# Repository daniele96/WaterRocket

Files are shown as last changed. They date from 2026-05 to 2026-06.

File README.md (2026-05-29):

# Water Rocket 🚀💧

Progetto di un razzo ad acqua (water rocket): documentazione completa di fisica,
componenti, materiali, calcoli, costruzione, lancio, sicurezza, risorse e stampa 3D.

## 📄 Documentazione

La guida completa è in **[WaterRocket.md](WaterRocket.md)** e include:

- **Come funziona** — principio di azione-reazione e formule della spinta
- **Componenti** — corpo, ugello, ogiva, alette, zavorra, sistema di lancio
- **Materiali** — lista della spesa
- **Parametri di progetto** — riempimento, pressione, stabilità (CG vs CP)
- **Calcoli rapidi** — velocità di espulsione, frazione d'acqua ottimale
- **Costruzione** — passo-passo
- **Lancio e test** — procedura e tabella raccolta dati
- **Sicurezza** ⚠️
- **Link di documentazione** — risorse verificate (NASA, Air Command, WRA2, ...)
- **Stampa 3D** 🖨️ — cosa stampare, materiali e dove trovare i modelli STL

## ⚠️ Sicurezza

L'aria compressa è pericolosa. Usa solo bottiglie PET per bibite gassate, non superare
le pressioni consigliate, indossa occhiali protettivi e lancia all'aperto lontano da
persone. Attività per ragazzi solo sotto supervisione adulta.

## 🚦 Stato

Progetto in fase di documentazione/progettazione.

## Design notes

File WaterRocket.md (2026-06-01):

# Progetto Water Rocket 🚀💧

Documento di progettazione per un razzo ad acqua (water rocket): principi fisici,
componenti, materiali, calcoli, costruzione, lancio e sicurezza.

---

## 1. Come funziona

Un water rocket sfrutta il **principio di azione-reazione** (3ª legge di Newton).
La bottiglia viene riempita parzialmente d'acqua e pressurizzata con aria.
All'apertura del tappo, l'aria compressa spinge fuori l'acqua ad alta velocità:
l'espulsione della massa d'acqua genera una spinta che accelera il razzo verso l'alto.

Equazione della spinta (semplificata):

```
F = ṁ · v_e        (massa espulsa al secondo × velocità di espulsione)
v_e = sqrt(2 · ΔP / ρ_acqua)
```

dove:
- `ΔP` = differenza di pressione tra interno bottiglia e atmosfera [Pa]
- `ρ_acqua` ≈ 1000 kg/m³

---

## 2. Componenti principali

| Componente | Funzione |
|---|---|
| **Corpo (bottiglia)** | Serbatoio pressione + acqua. PET da bibita gassata |
| **Ugello (nozzle)** | Apertura del tappo da cui esce l'acqua |
| **Ogiva (nose cone)** | Punta aerodinamica, riduce la resistenza |
| **Alette (fins)** | Stabilità aerodinamica in volo |
| **Zavorra** | Massa in punta per spostare il baricentro avanti  |
| **Sistema di lancio** | Tappo di tenuta + meccanismo di rilascio |
| **Recupero (opzionale)** | Paracadute per atterraggio dolce |

---

## 3. Materiali (lista della spesa)

- 1–2 **bottiglie PET** da 1,5 L o 2 L (per bibite gassate — resistono alla pressione)
- **Cartoncino / polipropilene / Depron** per le alette
- **Pallina da tennis** o cono in cartoncino per l'ogiva
- **Nastro adesivo resistente** (telato/Tesa) e **colla a caldo**
- **Plastilina o sabbia** per la zavorra
- **Tappo forato + valvola** (es. tappo gonfiabile / adattatore per pompa)
- **Pompa da bicicletta** con manometro
- **O-ring / guarnizione** per la tenuta
- Fascette, tubo in PVC per la rampa di lancio

---

## 4. Parametri di progetto consigliati

| Parametro | Valore tipico / di partenza |
|---|---|
| Volume bottiglia | 1,5 – 2 L |
| Riempimento d'acqua | **~1/3 del volume (25–40%)** |
| Pressione di lancio | 4 – 6 bar (max ~8 bar con PET) |
| N° alette | 3 o 4, distribuite simmetricamente |
| Posizione baricentro (CG)  | **davanti** al centro di pressione (CP) |
| Margine di stabilità | CG-CP ≈ 1–2 calibri (diametri) |

> ⚠️ **Regola d'oro stabilità:** il baricentro (CG) deve stare *davanti* (verso
> l'ogiva) rispetto al centro di pressione aerodinamica (CP). Per questo si aggiunge
> zavorra in punta. Verifica con la "prova della cordicella": appendi il razzo
> orizzontalmente al CG e fallo ruotare — deve volare con la punta in avanti.

---

## 5. Calcoli rapidi

**Velocità di espulsione acqua** (a 6 bar = 600 000 Pa):
```
v_e = sqrt(2 · 600000 / 1000) ≈ 34,6 m/s
```

**Stima frazione d'acqua ottimale:** il massimo della quota si ottiene quando c'è
abbastanza acqua da spingere a lungo, ma non così tanta da appesantire il razzo.
In pratica **~30% del volume** è un ottimo punto di partenza; ottimizza con i test.

**Quota:** dipende da pressione, massa a vuoto, aerodinamica e attrito.
Per simulazioni più precise puoi usare un foglio di calcolo o software dedicati
(vedi sezione 8).

---

## 6. Costruzione (passo-passo)

1. **Corpo:** scegli una bottiglia integra, senza ammaccature o graffi profondi.
2. **Alette:** ritaglia 3–4 alette identiche; incollale a 120° (o 90°) vicino
   all'ugello, ben allineate all'asse. Allineamento preciso = volo dritto.
3. **Ogiva:** fissa il cono/pallina in punta; inserisci la zavorra all'interno.
4. **Tenuta:** monta il tappo con valvola e o-ring; verifica che tenga la pressione.
5. **Bilanciamento:** trova il CG e controlla il margine di stabilità (sez. 4).
6. **Recupero (opz.):** aggiungi un paracadute con meccanismo a tempo o aerodinamico.

---

## 7. Lancio e procedura di test

1. Posiziona la rampa su terreno aperto, lontano da persone, edifici, linee elettriche.
2. Riempi d'acqua (~1/3) e fissa il razzo al sistema di lancio.
3. Pressurizza **gradualmente** controllando il manometro.
4. **Allontana tutti** ad almeno 5–10 m. Conto alla rovescia.
5. Rilascia da distanza di sicurezza (cordino/leva).
6. **Registra i dati** ad ogni lancio per ottimizzare:

| Lancio | Acqua (%) | Pressione (bar) | Massa (g) | Quota stimata (m) | Note |
|---|---|---|---|---|---|
| 1 | | | | | |
| 2 | | | | | |
| 3 | | | | | |

---

## 8. Strumenti utili

- **Simulatori:** *Water Rocket Fun*, *Clive's Water Rocket Simulator*, fogli Excel dedicati.
- **Misura quota:** app inclinometro + triangolazione, o altimetro a bordo (es. modulo BMP280).
- **Slow motion** dello smartphone per analizzare il distacco e la traiettoria.

---

## 9. ⚠️ Sicurezza (leggere SEMPRE)

- L'aria compressa è **pericolosa**: una bottiglia che cede a 6 bar può ferire.
- Usa **solo** bottiglie PET per bibite gassate, mai bottiglie danneggiate o riutilizzate troppe volte.
- **Non superare** le pressioni consigliate; non sostare mai sopra/davanti al razzo carico.
- Indossa **occhiali protettivi** durante la pressurizzazione.
- Lancia all'aperto, lontano da persone, animali e ostacoli. Mai al chiuso.
- Attività adatta a ragazzi **solo sotto supervisione adulta**.

---

## 10. Idee di miglioramento

- Razzo **bi-stadio** (due bottiglie in sequenza).
- **Tromboncino/booster** con bottiglie unite per più volume.
- Sistema di **recupero a paracadute** automatico.
- **Telemetria** a bordo (altimetro, accelerometro, GPS).
- Ottimizzazione aerodinamica dell'ogiva e delle alette.

---

## 11. Link di documentazione e risorse

> ⚠️ Gli URL possono cambiare nel tempo: se un link è morto, cerca il nome del sito/progetto.

### Guide, teoria e community
- **NASA – Water Rocket / Bottle Rocket** (principi fisici e attività didattiche):
  <https://www.grc.nasa.gov/www/k-12/rocket/BottleRocket/about.htm>
- **Air Command Water Rockets** (uno dei riferimenti storici più completi,
  con build avanzate, multistadio, recupero): <https://www.aircommandrockets.com/>
  - Quanta acqua mettere: <http://www.aircommandrockets.com/water.htm>
  - Costruire un lanciatore: <http://www.aircommandrockets.com/rocket_launcher.htm>
  - Costruzione del razzo: <http://www.aircommandrockets.com/construction.htm>
  - Meccanismo di recupero paracadute (DetMech): <http://www.aircommandrockets.com/howitworks_3.htm>
  - Galleria progetti: <http://www.aircommandrockets.com/rocket_gallery.htm>
  > Nota: il sito funziona anche su `http://` se l'`https://` dà problemi.
- **NPL / The Water Rocket Achievement World Record Association (WRA2)**
  (record, regole, tecnica): <https://www.wra2.org/>
- **r/WaterRockets** (community Reddit con build e consigli):
  <https://www.reddit.com/r/WaterRockets/>
- **Wikipedia – Water rocket** (panoramica generale e riferimenti):
  <https://en.wikipedia.org/wiki/Water_rocket>

### Simulatori e calcolo
- **Clive's Water Rocket Simulator (Excel)** — molto usato per stimare quota e profilo di volo.
- **OpenRocket** (più orientato ai razzi a propellente solido, ma utile per concetti di
  stabilità/CG-CP): <https://openrocket.info/>
- **Water Rocket Fun** — app/simulatore per il calcolo del riempimento ottimale.

### Video tutorial (cerca su YouTube)
- "Water rocket build" / "water rocket launcher Gardena" (lanciatore con attacco rapido da giardino)
- "Water rocket parachute deployment" per i sistemi di recupero
- Canale **Air Command Rockets** su YouTube

---

## 12. Stampa 3D 🖨️

La stampa 3D è perfetta per le parti **non in pressione**: ogiva, alette, anelli
fermaaletta, adattatori per la rampa e meccanismi di recupero. **La camera in pressione
deve restare la bottiglia PET** (il PLA/PETG stampato non è affidabile per contenere
4–8 bar).

### Cosa conviene stampare
| Parte | Materiale consigliato | Note |
|---|---|---|
| Ogiva / nose cone | PLA o PETG | Leggera; eventualmente cava per zavorra |
| Anello porta-alette (fin can)| PETG / ABS / ASA | Si infila sul collo o sul corpo |
| Alette | PETG / PLA | Anche stampabili a parte e incastrate |
| Adattatore ugello / launcher | PETG / ABS | Per accoppiare la rampa al collo bottiglia |
| Vano paracadute / nose lock  | PLA / PETG | Per il sistema di recupero |

> Per parti soggette a sole e calore preferisci **PETG/ASA** (il PLA si deforma al caldo
> e diventa fragile dopo gli urti).

### Dove trovare i modelli (STL già pronti)
- **Printables** (Prusa): <https://www.printables.com/> → cerca *"water rocket"*, *"water rocket fins"*, *"nose cone"*
- **Thingiverse**: <https://www.thingiverse.com/search?q=water+rocket> → moltissimi fin can e ogive
- **Thangs**: <https://thangs.com/> → motore di ricerca multi-piattaforma di modelli 3D
- **MakerWorld** (Bambu Lab): <https://makerworld.com/> → cerca *"water rocket"*
- **Cults3D**: <https://cults3d.com/> → modelli gratuiti e a pagamento
- **GrabCAD** (modelli CAD parametrici, utili da modificare):
  <https://grabcad.com/library> → cerca *"water rocket"*

### Termini di ricerca utili
`water rocket fins`, `water rocket nose cone`, `bottle rocket fin can`,
`water rocket launcher adapter`, `Gardena water rocket launcher`,
`PET bottle rocket parachute`, `water rocket coupling 2 liter`.

### Suggerimenti di stampa
- Stampa le alette **piatte sul piatto** per la massima resistenza lungo la corda.
- Per il fin can usa **alta densità di riempimento** vicino agli attacchi (o pareti spesse).
- Modella l'**interno dell'ogiva cavo** per inserire la zavorra (plastilina/sabbia) e
  regolare il baricentro.
- Verifica il **diametro del collo bottiglia standard PCO-1810/PCO-1881** quando progetti
  adattatori parametrici.

---

## 13. Elettronica di bordo 🔌

Sistema di telemetria + log dati + video da montare nell'**ogiva** del razzo
(scende col paracadute passivo del kit — vedi §3 e nota sotto).

### Architettura

- **MCU di volo**: ESP32-S3 con camera, in ogiva
- **Sensori I2C** sullo stesso bus: BMP280 + MPU6050
- **Storage**: microSD per log ad alta frequenza + video
- **Recupero**: passivo (paracadute del kit) + buzzer ritrovamento
- **Telemetria**: WiFi/BLE live a terra (range utile ~50 m)

### Board scelta: Seeed XIAO ESP32-S3 Sense

| Caratteristica | Valore |
|---|---|
| Dimensioni / peso | 21×17,5 mm, ~3 g |
| Camera | OV2640 2 MP (staccabile, opz. OV5640) |
| Microfono | PDM digitale |
| microSD slot | Sì, sulla shield camera |
| PSRAM / Flash | 8 MB / 8 MB |
| Carica LiPo | Sì, pad **BAT+/BAT-** da saldare |
| Wireless | WiFi 2,4 GHz + BLE 5.0, antenna ceramica + IPEX |
| Riferimento firmware | usata dal progetto `tritonFC` |

### Sensori e funzionalità sbloccate

| Sensore | Bus | Cosa abilita | Priorità |
|---|---|---|---|
| **BMP280** | I2C | Quota live, apogeo, profilo di volo, T/P cabina | ⭐⭐⭐ |
| **MPU6050** | I2C | Accelerazione lancio, giroscopio (roll/yaw/pitch), rilevazione apogeo via segno accel | ⭐⭐⭐ |
| **microSD** (slot integrato) | SPI | Log ≥100 Hz + video AVI | ⭐⭐⭐ |
| **Camera OV2640** | DVP | Video 640×480 a 15–25 fps, foto, analisi traiettoria | ⭐⭐ |
| **Buzzer passivo** | GPIO PWM | Beep ritrovamento + codici di stato | ⭐⭐ |
| **LED ultra-bright** | GPIO | Visibilità slow-mo, stato armato/disarmato | ⭐ |
| **Microfono PDM** | I2S | Acustica del getto d'acqua, evento apertura paracadute | ⭐ |
| **RTC DS3231** (lab) | I2C | Timestamp assoluti, sincronizzazione multi-razzo | ⭐ |
| **BH1750 / TSL2591** (lab) | I2C | Profilo luminosità lungo la traiettoria (didattico) | ⭐ |
| **GPS NEO-M8N** | UART | Ritrovamento a distanza (≥70 m). Costa ~20 g | ⭐ opz |
| **ADXL375 ±200 g** | I2C | Vero picco accel lancio + impatto (MPU6050 satura a ±16 g) | ⭐ opz |

### Schema collegamenti minimo

```
XIAO ESP32-S3 Sense
├── I2C (SDA/SCL)
│   ├── BMP280   (addr 0x76 o 0x77)
│   └── MPU6050  (addr 0x68)
├── microSD       → slot integrato (shield camera)
├── Camera OV2640 → FPC dedicato
├── BAT+ / BAT-   → LiPo 1S 300–400 mAh (saldatura)
├── GPIO          → buzzer passivo + LED
└── USB-C         → programmazione + ricarica
```

### Sensori del lab da NON portare in volo

| Sensore | Perché no | Uso alternativo |
|---|---|---|
| DHT11 | Risposta 2 s, volo dura ~5 s | Stazione meteo a terra |
| MQ-135 | Preriscaldo 30 s, alto consumo | Stazione a terra |
| LiPo 2000 mAh | ~40 g, penalizza la quota | Ground station / banco |

### Posizionamento meccanico

Elettronica **nell'ogiva** (verde del kit AliExpress, o sostitutiva stampata 3D più
capiente — vedi §12). L'ogiva si stacca all'apogeo per inerzia, gli elastici cedono
e tira fuori il paracadute; scende legata al corpo via shock cord. **Annegare PCB e
LiPo in spugna densa** dentro un vano dedicato. LiPo **sempre fissata** con biadesivo
o fascette, mai libera.

### Architettura firmware suggerita

Sposa il modello didattico "un gruppo = un sensore" con task FreeRTOS separati:

```
[Task BMP280] ─┐
[Task MPU6050]─┼→ [Queue dati] → [Task Logger SD] + [Task Telemetria WiFi/BLE]
[Task Camera] ─┘
```

**Firmware di riferimento (open source):**
- **[zerneo85/ESP-Controlled-Rocket](https://github.com/zerneo85/ESP-Controlled-Rocket)** (GPL-3.0, attivo): BMP280 + MPU6050, Web UI, WebSocket live, 3D viewer, log SD. **Punto di partenza consigliato.**
- **[MaelStudio/tritonFC](https://github.com/MaelStudio/tritonFC)**: gira nativamente su XIAO ESP32-S3 Sense, gestisce video AVI, PCB di riferimento.
- **[nodebotsau/water-rocket](https://github.com/nodebotsau/water-rocket)** (MIT): ground station Node.js + MQTT, riusabile.

---

## 14. Acquisti e inventario 🛒

### Hardware fisico (razzo + lanciatore)

- [Kit lanciatore + paracadute AliExpress](https://it.aliexpress.com/item/1005008517820572.html)
  — paracadute passivo a *nose-cone pop-off*, fino a ~50–70 m reali

### Da acquistare (kit volante elettronica) — ~71 €

| # | Articolo | Q.tà | € | Link |
|---|---|---|---|---|
| 1 | **Seeed XIAO ESP32-S3 Sense** | 2 | 34 | [Amazon.it ✓](https://www.amazon.it/Seeed-Studio-XIAO-ESP32S3-Sense/dp/B0C69FFVHH) |
| 2 | **LiPo 1S 300–400 mAh JST 1.25** | 2 | 12 | [Amazon.it](https://www.amazon.it/s?k=LiPo+1S+400mAh+JST+1.25) · [AliExpress](https://it.aliexpress.com/w/wholesale-lipo-1s-400mah-jst-1.25.html) |
| 3 | **MPU6050 / GY-521** | 2 | 8 | [Amazon.it](https://www.amazon.it/s?k=GY-521+MPU6050) · [AliExpress](https://it.aliexpress.com/w/wholesale-gy-521-mpu6050.html) |
| 4 | **Buzzer passivo 5V** (multipack) | 1 kit | 6 | [Amazon.it](https://www.amazon.it/s?k=buzzer+passivo+5V+arduino) |
| 5 | **Antenna IPEX 2.4 GHz** (opzionale) | 2 | 6 | [Amazon.it](https://www.amazon.it/s?k=antenna+IPEX+UFL+2.4GHz) · [Seeed ufficiale](https://www.seeedstudio.com/2-4GHz-2-81dBi-Antenna-for-XIAO-ESP32C3-p-5475.html) |
| 6 | **LED + resistenze** (se mancanti) | 1 kit | 5 | [Amazon.it](https://www.amazon.it/s?k=led+kit+5mm+arduino) |
| | | **Totale** | **~71 €** | |

### Già in possesso (riusabile per il razzo)

| Pezzo | Q.tà | Uso nel razzo |
|---|---|---|
| ✅ BMP280 breakout | 5 | Altimetria di volo |
| ✅ microSD 32 GB | 5 | Log + video (slot della XIAO Sense) |
| ✅ ESP32-S3 DevKitC-1 (DUBEUYEW) | 2 | Ground station, test a banco, kit didattici |
| ✅ Freenove ESP32-WROVER + camera | 1 | Ground station / test pipeline camera |
| ✅ TTGO T-Display | 1 | Display a terra per telemetria live |
| ✅ BH1750, TSL2591 (luce) | 3 + 1 | Sensori opzionali (didattica) |
| ✅ RTC DS3231 | 5 | Timestamp log (opzionale) |
| ✅ LiPo 2000 mAh JST 1.25 | 4 | **Solo ground station** — troppo pesanti per volare |
| ✅ Breadboard + jumper + USB-C | — | Prototipazione |
| ✅ Stagno | — | Saldature (pad BAT della XIAO) |

### Sensori del lab esclusi dal volo

❌ DHT11, MQ-135, LiPo 2000 mAh, pannello solare — vedi §13 *"da NON portare in volo"*.

---

*Buoni lanci! 🚀*
```

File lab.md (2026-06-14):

# Laboratorio Water Rocket per Bambini e Ragazzi 🚀

Programma di laboratorio per evento didattico in cui i partecipanti
**assemblano, decorano e lanciano il proprio water rocket** a partire dal kit
acquistato ([AliExpress 1005008517820572](https://it.aliexpress.com/item/1005008517820572.html)).

Documento operativo per educatori/animatori. Per la teoria fisica e le specifiche
tecniche del razzo vedi [WaterRocket.md](WaterRocket.md).

---

## 0. Quadro generale

| Parametro | Valore di partenza |
|---|---|
| Età target | 8–14 anni |
| Dimensione gruppi | 3–4 bambini per razzo |
| **N° gruppi per sessione** | **4–6** (massimo gestibile da 1 educatore in 2h) |
| **Durata sessione** | **2 h** (incluso lancio e debrief) |
| **Bambini per sessione** | 12–24 |
| **Lanci per razzo** | **1–2** (un lancio principale, eventuale bis se c'è tempo) |
| **Scalabilità** | Sessioni **parallele** o **sfalsate** se più bambini — vedi §10 |
| Spazio richiesto | Aula/cortile per assemblaggio + campo aperto ≥30×30 m per lanci |
| Supervisione adulta | **Obbligatoria** durante pressurizzazione e lancio |

**Decisione aperta:** uso del **paracadute** (incluso nel kit) ancora da confermare.
Le fasi sotto sono pensate per funzionare **in entrambi gli scenari** — vedi
note specifiche in §5.

---

## 1. Materiali per il lab (per gruppo)

### Forniti dal kit AliExpress
- Bottiglia (da portare separatamente — PET 1,5 L o 2 L da bibita gassata)
- Ogiva verde + elastici di tenuta
- Paracadute (opzionale a discrezione organizzazione)
- Lanciatore manuale condiviso tra i gruppi

### Da preparare in stazione lab

| Materiale | Quantità per gruppo | Note |
|---|---|---|
| **Cartone ondulato da imballo** | 1 scatola A4 | Per pinne — riciclato, gratis (vedi §4) |
| **Nastro da pacchi trasparente** (larghezza 5 cm) | 1 rotolo condiviso | Laminatura pinne (impermeabilizzazione) |
| **Sagome pinne stampate** | 3 modelli (S/M/L) | Cartamodello pre-disegnato |
| **Striscia di carta** 3×35 cm + matita | 1 | Per metodo della striscia (vedi §4) — adattabile a qualsiasi bottiglia |
| **Washi tape colorato** | 2–3 rotoli | Decoro corpo |
| **Pennarelli Posca / Sharpie oil** | Set condiviso | Scrivere su PET |
| **Bi-adesivo schiumoso (foam tape)** | 1 striscia 30 cm | Incollaggio pinne, sicuro |
| **Plastilina pre-pesata** | Bustine da 10 / 20 / 30 g | Zavorra ogiva |
| **Spago + nastro** | 1 m | Per test della cordicella |
| **Forbici a punta tonda** | 2–3 | Sicurezza bambini, tagliano anche il cartone |

---

## 2. Struttura del laboratorio (sessione singola 2 h)

Sequenza compatta per 4–6 gruppi in 120 minuti netti.

```
[Briefing iniziale]                10'
   ↓
[Stazione 1: Pinne]                25'
   ↓
[Stazione 2: Decoro & identità]    20'
   ↓
[Stazione 3: Bilanciamento]        15'
   ↓
[Spostamento al campo lanci]        5'
   ↓
[Stazione 4: Lancio (4-6 razzi)]   35'
   ↓
[Debrief + dati]                   10'
─────────────────────────────────────
TOTALE                            120'
```

| Fase | Durata | Note per restare nei tempi |
|---|---|---|
| Briefing | 10' | Cartelloni pre-pronti, demo palloncino veloce |
| Pinne | 25' | Sagome pre-tagliate dall'organizzatore + bi-adesivo (no colla a caldo) |
| Decoro | 20' | Stop netto allo scadere — è la fase che dilata di più |
| Bilanciamento | 15' | Plastilina pre-pesata in bustine, test della cordicella rapido |
| Lancio | 35' | ~6 min per razzo (riempimento + pressurizzazione + lancio + reset) |
| Debrief | 10' | Tabella dati su lavagna, foto di gruppo |

> ⚠️ **Se hai 5–6 gruppi non puoi compressare il lancio sotto i 30–35 min** senza
> sacrificare sicurezza. Se vuoi più gruppi per sessione, vedi §10.

---

## 3. Briefing iniziale (10 min)

Spiegazione semplice davanti a tutti i gruppi insieme:

1. **Come vola un water rocket** (azione-reazione, 2 minuti, niente formule).
   *Dimostrazione:* palloncino gonfio rilasciato → reazione visibile.
2. **Tre regole d'oro** (scritte su un cartellone, restano visibili tutto il lab):
   - 🎯 **Simmetria**: tutto deve essere bilanciato attorno all'asse
   - 🎯 **Punta avanti**: il baricentro deve stare davanti
   - 🎯 **Niente parti dure sporgenti**: a 100 km/h diventano proiettili
3. **Spiegazione test della cordicella** (vedi §6): "solo i razzi che superano
   questo test possono lanciare." → crea un obiettivo chiaro.
4. **Sicurezza al lancio** (vedi §7).

---

## 4. Stazione 1: Costruzione pinne (25 min)

### Obiettivo didattico
I ragazzi capiscono **perché** servono le pinne (stabilità aerodinamica) e
**come** la geometria influisce sul volo.

### Procedura
1. Ogni gruppo sceglie una sagoma tra le 3 disponibili (small/medium/large)
   → spiegare il trade-off: pinne grandi = più stabili ma più peso/attrito.
2. Ritaglio di **3 o 4 pinne identiche** (raccomandato 4 per principianti,
   è più tollerante agli errori di simmetria).
3. **Metodo della striscia** per posizionare le pinne a 90°/120° su *qualsiasi*
   diametro di bottiglia (non tutte le PET hanno lo stesso diametro: Coca-Cola
   ≠ Levissima ≠ Schweppes):
   - Avvolgi una striscia di carta attorno alla bottiglia, segna col matita il
     punto di sovrapposizione → hai la circonferenza esatta.
   - Taglia o piega sul segno; piega la striscia "a fisarmonica" in **3 parti
     uguali** (per 3 pinne) o **4 parti uguali** (per 4 pinne — basta piegare
     in due e poi ancora in due).
   - Riavvolgi sulla bottiglia, segna sulla PET con pennarello cancellabile i
     punti dove cadono le pieghe → eccoli, perfettamente equidistanti.
   - Incolla le pinne su quei segni.

   > 📐 **Mini-lezione di geometria**: i ragazzi capiscono *perché* funziona
   > (la circonferenza si divide in parti uguali) — è la stessa idea del
   > tagliare una pizza in fette identiche senza compasso.

   **Alternativa veloce (elastico universale):** elastico piatto largo 10–15 mm
   pre-marcato col Posca a 3 o 4 punti equidistanti. Si stira sulla bottiglia
   adattandosi a qualsiasi diametro, le pinne si allineano ai punti. Riusabile
   tra gruppi ed eventi (~5 € per 10 elastici). Meno didattico ma più rapido se
   il tempo stringe.
4. Incollaggio con **bi-adesivo schiumoso** (sicuro, niente colla a caldo per
   i più piccoli) o colla a caldo gestita dall'adulto per i più grandi.
5. **Verifica allineamento**: appoggiare il razzo su un tavolo piatto → le pinne
   devono toccare tutte il piano contemporaneamente. Se no, raddrizzare.

### Errore più comune
Pinne diverse tra loro o disallineate rispetto all'asse → razzo che gira come
una trottola. L'anello guida lo previene.

### Materiale pinne: quale scegliere

**Raccomandato: cartone ondulato da imballo + nastro da pacchi trasparente**

Costo zero (cartone riciclato da scatole Amazon/spesa), taglio gestibile dai
bambini con le forbici, decorabilità massima. Il nastro da pacchi sigilla
fronte/retro la pinna rendendola **impermeabile**, e diventa esso stesso un
mini-step didattico ("impermeabilizzazione, come i tetti e le navi").

#### Procedura laminatura pinne (5 min/gruppo, integrata nella stazione)

1. Ritaglia la pinna in cartone seguendo la sagoma stampata.
2. Adagia la pinna su una striscia di **nastro da pacchi trasparente** larga 5 cm.
3. Risvolta il nastro sopra la pinna → entrambi i lati sigillati.
4. Rifila l'eccedenza di nastro con le forbici.

Risultato: pinna impermeabile, lucida, riusabile per 5–10 lanci — più che
sufficiente visto che ogni razzo farà **1–2 lanci** soltanto. La laminatura
resta comunque consigliata per gestire gli schizzi inevitabili durante riempimento
e pressurizzazione, e per atterraggi su erba bagnata.

#### Confronto materiali

| Materiale | Acqua-resistente | Taglio bambini | Costo | Riusabile | Voto |
|---|---|---|---|---|---|
| **Cartone ondulato + nastro pacchi** ⭐ | Sì (laminato) | ✅ forbici | **Gratis** | 5–10 lanci | **Migliore per il lab** |
| Polipropilene corex 2-3 mm | Sì nativo | ⚠️ cutter (adulto) | 3–5 €/foglio A3 | 30+ lanci | Ottimo se evento ricorrente |
| Depron / foamboard 3 mm | No (si rovina umido) | ✅ forbici | ~5 €/foglio | Limitato | Leggero ma fragile |
| Cartoncino 500 g/m² laminato | Sì (laminato) | ✅ forbici | ~1 € | 1–2 lanci | Per bambini piccoli |
| Plastica da fondo bottiglia PET | Sì nativo | ⚠️ bordi taglienti | Gratis | Sì | Laborioso |
| Balsa / compensato 1-2 mm | No | ❌ adulti | Medio | Sì | Look pro, ragazzi grandi |
| Gomma crepla / EVA foam | Sì | ✅ | Basso | No | ❌ **flette in volo, scartare** |
| PLA stampato 3D | Sì | N/A | Variabile | Sì | Toglie la STEM-activity |

**Perché il cartone vince per il lab dei bambini:**
- **Costo zero** → scala a qualunque numero di partecipanti senza incidere sul budget
- **Taglio con forbici** → autonomia dei bambini, niente adulti dedicati al cutter
- **Decorabilità totale** → tempera, pastelli, pennarelli, gessetti, di tutto prima della laminatura
- **Storia ecologica** → "stiamo riciclando una scatola Amazon per costruire un razzo"
- La **laminatura diventa un mini-laboratorio di impermeabilizzazione**

**Quando preferire il polipropilene corex**: se prevedi di riusare le stesse
pinne in più eventi nell'anno, o vuoi un look uniforme e "professionale". Il
corex resta valido come alternativa, soprattutto per la **variante avanzata**
(§11) con razzi strumentati che faranno decine di lanci.

**Reperimento del cartone**: scatole Amazon/spesa/scarpe. Privilegia cartone
**a singola onda**, spesso 2–3 mm — più rigido e leggero del doppia onda.

---

## 5. Stazione 2: Decoro e identità (20 min)

### Obiettivo
I ragazzi si "appropriano" del razzo. Massima libertà creativa **dentro le tre
regole d'oro**.

### Attività
1. **Washi tape** colorato per fasce sul corpo → leggero, peel-off pulito.
2. **Pennarelli Posca / Sharpie oil-based** per nome del gruppo, numero, scritte
   ("Astro-3", "Fulmine", "Razzo X"). Aderiscono al PET.
3. **Disegni / loghi** ritagliati in carta + foam tape simmetrico (uno per lato).
4. **Personalizzazione del paracadute** (se lo usate): pennarelli per stoffa
   sulla seta colorata, nome del gruppo.
5. **Bandierina** in cartoncino fissata in testa? **NO**: aumenta drag asimmetrica.
   Meglio una decorazione *attorno* all'ogiva, simmetrica.

### Regole imposte dall'educatore
- ❌ Niente decorazione sopra il giunto ogiva/corpo che impedisca la separazione
  (anche se non usate il paracadute oggi, magari lo usate al prossimo evento).
- ❌ Niente oggetti pesanti, rigidi o sporgenti (LEGO, plastiche).
- ❌ Niente decorazioni asimmetriche: ogni adesivo da un lato → uno identico
  dall'altro.
- ✅ **Colori sgargianti** (giallo/arancione/rosso): aiutano a ritrovare il razzo.

---

## 6. Stazione 3: Bilanciamento + Test della cordicella (15 min)

### Obiettivo
Far scoprire ai ragazzi il concetto di **baricentro** e di **stabilità**
attraverso un test pratico.

### Procedura
1. **Aggiungere zavorra**: bustina di plastilina nell'ogiva (partire con 20 g).
2. **Trovare il CG**: bilanciare il razzo su un dito → segnare con pennarello
   il punto dove sta in equilibrio.
3. **Test della cordicella**:
   - Legare uno spago al razzo nel punto del CG (centro di gravità).
   - Far roteare il razzo orizzontalmente sopra la testa (in spazio aperto, con
     attenzione).
   - 🟢 **Se la punta va in avanti** durante la rotazione → razzo stabile, OK.
   - 🔴 **Se il razzo gira o va di coda** → instabile: aggiungere altri 10 g di
     plastilina in punta e ripetere.
4. **Solo i razzi che superano il test** procedono al lancio.

### Discussione guidata
"Perché serve peso davanti? Perché le pinne stanno dietro?" — i ragazzi
arrivano da soli al concetto: *come una freccia, il peso sta avanti e le piume
dietro*.

---

## 7. Stazione 4: Lancio (35 min, all'aperto)

### Setup sicurezza
- **Area di lancio recintata** con coni o nastro: raggio minimo **10 m**, idealmente 15.
- **Spettatori e altri gruppi a distanza ≥10 m**, perpendicolarmente al vento.
- **Occhiali protettivi** per chi pressurizza (almeno l'adulto operatore).
- **Pressione massima 5 bar** in contesto bambini (il manuale del kit dichiara di più,
  ma 5 bar = già 40-50 m di quota e impatti gestibili).
- **Vento massimo 15 km/h** — oltre, il razzo deriva troppo.

### Lanci per razzo

Ogni razzo va lanciato **1 volta** come obiettivo principale; un **secondo lancio**
("bis") è previsto solo se la sessione è in anticipo sui tempi e tutti i gruppi
hanno già completato il primo. Questo semplifica la pianificazione, riduce
l'usura del materiale e mantiene il **lancio come momento speciale**, non come
attività ripetitiva.

### Procedura standard per ogni lancio
1. Gruppo presenta il proprio razzo (nome, decoro) — momento "spettacolo".
2. Riempimento d'acqua a **~1/3 del volume** (segno pre-tracciato sulla bottiglia
   per i bambini).
3. Razzo fissato sulla rampa **dall'adulto**.
4. Pressurizzazione **graduale** (l'adulto pompa, manometro visibile).
5. Conto alla rovescia da 5 — tutto il gruppo a voce alta → **lancio!**
6. **Tutti restano dentro l'area sicura** finché il razzo non è atterrato.
7. Recupero del razzo (sempre da adulti, per primi).

### Scenario A — **CON paracadute**
- L'ogiva si stacca all'apogeo per inerzia, il paracadute si apre, discesa lenta
  (4–6 m/s).
- Elettronica può essere imbarcata (vedi [WaterRocket.md §13](WaterRocket.md)).
- Razzo riutilizzabile per più lanci.

### Scenario B — **SENZA paracadute**
- Discesa balistica → impatto a 25–35 m/s.
- **Niente elettronica a bordo** (si rompe garantito).
- **Bottiglia si ammacca** dopo 2–3 lanci, va sostituita.
- ✅ Lab più semplice: niente da piegare/preparare, nessun punto di fallimento.
- ⚠️ Va comunque **mantenuto il perimetro di sicurezza** — il razzo che ricade
  può fare male.
- Suggerimento: organizzarsi per avere **bottiglie PET di scorta** già pronte.

### Tabella dati (compilata dai ragazzi)

Su lavagna o foglio condiviso:

| Gruppo | Razzo | Acqua (%) | Pressione (bar) | Quota stimata (m) | Note |
|---|---|---|---|---|---|
| 1 | | | | | |
| 2 | | | | | |
| ... | | | | | |

**Stima quota:** triangolazione semplice con app inclinometro
(es. *Theodolite*, *AngleMeter*) da 30 m di distanza al momento dell'apogeo.

---

## 8. Debrief finale (10 min)

- Quale razzo è andato più in alto? **Perché?** (poca acqua / più pressione /
  pinne grandi / più zavorra…)
- Quale razzo ha volato più dritto? **Perché?** (simmetria pinne / bilanciamento)
- Cosa cambieresti al tuo razzo per il prossimo lancio?

→ Mini-tabella con le **variabili modificate** dai gruppi per il volo successivo:
diventa un piccolo metodo scientifico.

---

## 9. Logistica e checklist (per organizzatori)

### Settimana prima
- [ ] Acquisto kit AliExpress (~3 settimane di lead time)
- [ ] Acquisto fogli polipropilene corex (Amazon o ferramenta)
- [ ] Stampa sagome pinne (3 taglie × N gruppi)
- [ ] Stampa anelli guida 120° in cartoncino
- [ ] Plastilina porzionata in bustine
- [ ] Verifica meteo previsto

### Giorno del lab
- [ ] Bottiglie PET (1,5 o 2 L per bibita gassata) — chiedere ai partecipanti
  di portarle, o averne di scorta
- [ ] Pompa con manometro testata
- [ ] Lanciatore montato e testato (1 lancio di prova *senza* bambini intorno)
- [ ] Asciugamani / panni (acqua dappertutto)
- [ ] Kit pronto soccorso
- [ ] Telecamera/smartphone per documentare i lanci (slow-mo!)

### Materiale didattico stampato
- [ ] Cartellone "3 regole d'oro"
- [ ] Cartellone "test della cordicella"
- [ ] Schede dati per ogni gruppo
- [ ] Schema CG vs CP semplificato

---

## 10. Scalabilità: sessioni parallele e sfalsate 🔁

Una sessione singola da 2 h gestisce **12–24 bambini** (4–6 gruppi). Per numeri
maggiori esistono **due strategie**, eventualmente combinabili.

### 📊 Dimensionamento rapido

| Bambini totali | Strategia consigliata | Educatori | Lanciatori |
|---|---|---|---|
| ≤24 | 1 sessione singola | 1 + 1 al lancio | 1 |
| 25–48 | **2 sessioni parallele** o **2 sfalsate** | 2 + 1 al lancio | 1–2 |
| 49–72 | **3 sessioni parallele** sfalsate sul lancio | 3 + 1 al lancio | 1–2 |
| 73–100 | **3–4 parallele** + 2 lanciatori | 4 + 2 al lancio | 2 |
| >100 | Spezza in più turni nella giornata (mattina/pomeriggio) | scala linearmente | ≥2 |

### Strategia A — Sessioni **parallele** (tante stanze, lancio sfalsato)

Più sessioni partono **insieme** in stanze/aree diverse, ognuna con il proprio
educatore. **Il lancio è il collo di bottiglia** perché serve un solo lanciatore
sicuro a vista.

```
Tempo  →   0    10   30   50   65   70  105   115  120 min
Sess. A   [Br] [Pin] [Dec] [Bil] [→] [LANCIO 35'] [Deb]
Sess. B   [Br] [Pin] [Dec] [Bil] [→] [attesa  ] [LANCIO 35'] ← sfalsata di 35'
```

**Quando funziona bene:**
- Hai più stanze/zone separate per assemblaggio
- Hai 1 educatore per sessione + 1 dedicato al lancio
- 1 solo lanciatore va bene (il bottleneck si sfalsa)

**Adattamento per 2 sessioni parallele:**
- Sessione A briefing alle 9:00 → lancio alle 10:25
- Sessione B briefing alle 9:00 → bilanciamento più lungo → lancio alle 11:00
- O più semplicemente: **partenza sfalsata di 30–40 min** (vedi Strategia B)

### Strategia B — Sessioni **sfalsate** (stesso spazio, partenze scaglionate)

Le sessioni si succedono ogni 30–40 min sullo stesso spazio fisico. Quando A è
al lancio, B sta finendo bilanciamento, C inizia il briefing.

```
Tempo  →   0     30    60     90    120   150   180 min
Sess. A   [-------Sess. A 2h------]
Sess. B            [-------Sess. B 2h------]
Sess. C                    [-------Sess. C 2h------]
```

**Pro:** richiede meno spazio (1 area) e meno lanciatori (1 condiviso).
**Contro:** richiede più ore in totale e personale che ruota.

### Risorse — cosa duplicare per sessione parallela

| Risorsa | Per sessione | Condivisibile? | Note |
|---|---|---|---|
| Educatore principale | 1 | ❌ | 1 per sessione |
| Educatore al lancio | — | ✅ | 1 dedicato per tutto l'evento |
| **Lanciatore (kit AliExpress)** | — | ✅ se sfalsate | 1 ogni 1–2 sessioni in parallelo |
| Pompa con manometro | 1 per lanciatore | ❌ | |
| Tavolo lavoro | 1 per gruppo | ❌ | 4–6 per sessione |
| Sagome pinne / striscia carta | 1 per gruppo | ❌ | Stampa in massa |
| Plastilina porzionata | 1 set per gruppo | ❌ | Pre-pesata a casa |
| Bottiglie PET di scorta | 2–3 per sessione | ❌ | Se senza paracadute, anche di più |

### Costo aggiuntivo per ogni lanciatore extra

Acquistando un secondo kit AliExpress: ~40 € (solo il lanciatore, le decorazioni
e il paracadute restano disponibili come scorta).

### ⏰ Briefing iniziale condiviso (ottimizzazione)

Se hai 2–3 sessioni che partono insieme, **fai un briefing comune di 15 min**
con tutti i bambini riuniti (cartelloni grandi, demo unica). Risparmi 10 min per
sessione e crei "evento corale" all'inizio. Poi i gruppi si dividono nelle aule.

---

## 11. Variante avanzata (per ragazzi più grandi, 12+)

Aggiungere una **5ª stazione opzionale di elettronica**:
- 1 razzo "spia" con XIAO ESP32-S3 Sense in ogiva (vedi [WaterRocket.md §13](WaterRocket.md))
- Registra video del volo e dati di quota/accelerazione
- A debrief si analizzano i dati reali del volo → confronto con stime visive
- **Richiede paracadute** per non rompere l'elettronica

Costo aggiuntivo per ~1 razzo strumentato: ~50 € una tantum (la board si riusa).

---

*Buon lancio a tutti i razzi! 🚀💧*

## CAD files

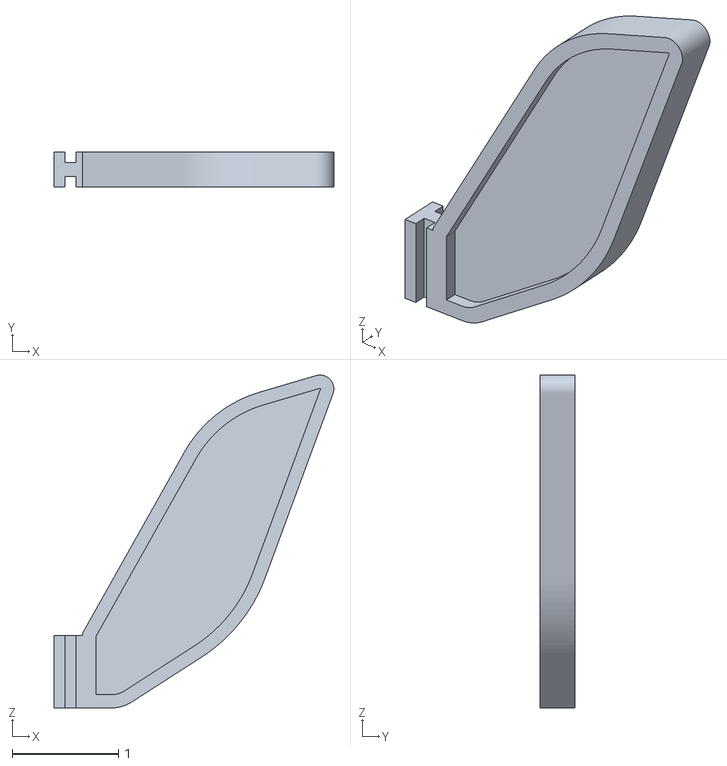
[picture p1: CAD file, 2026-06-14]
3dModels/Fins Rev. 2.stl
2.63 x 0.333 x 3.13

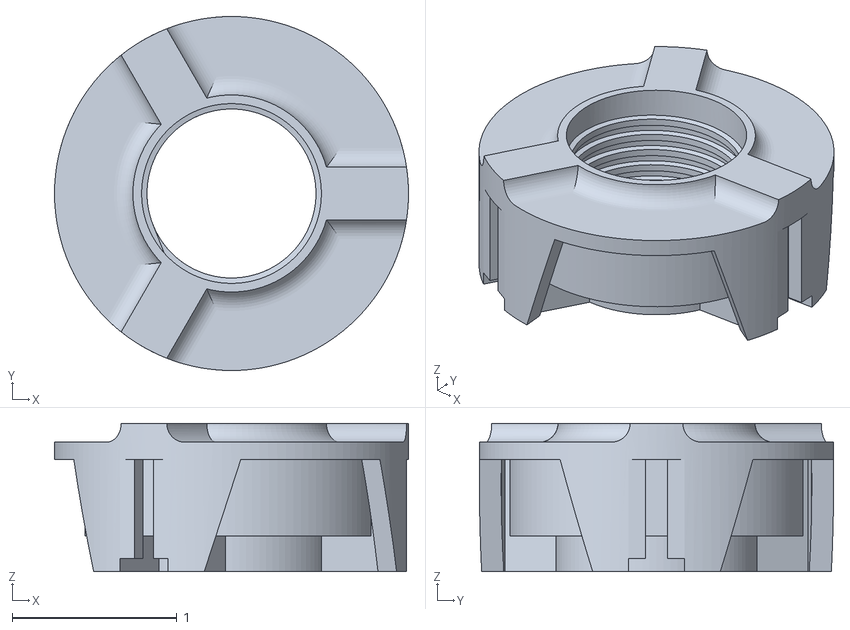
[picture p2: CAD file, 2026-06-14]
3dModels/Soda Bottle Base Rev. 2.stl
2.15 x 2.15 x 0.9

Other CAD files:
3dModels/Fins Rev. 3 (corpo pieno + aggancio v2).stl

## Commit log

2026-05-29 Initial commit: documentazione progetto Water Rocket
    Aggiunge WaterRocket.md con fisica, componenti, materiali, calcoli,
    costruzione, lancio, sicurezza, link di documentazione verificati e
    risorse per la stampa 3D.
2026-05-29 Add .gitignore e rimuovi .claude/ dal tracking
    Esclude i file di configurazione locale di Claude Code, OS ed editor.
2026-06-01 Add sezione elettronica di bordo e inventario acquisti
    Aggiunte §13 (Elettronica di bordo) con scelta board XIAO ESP32-S3 Sense,
    tabella sensori e funzionalità sbloccate, schema collegamenti e firmware di
    riferimento; §14 (Acquisti e inventario) con BOM kit volante, link diretti e
    inventario riusabile dal lab precedente.
2026-06-14 Add laboratorio bambini e modelli 3D di pinne e base bottiglia
    Aggiunto lab.md con programma operativo del laboratorio per evento didattico:
    4 stazioni (pinne, decoro, bilanciamento, lancio), materiale consigliato
    (polipropilene corex), metodo della striscia di carta per posizionare le pinne
    su qualsiasi diametro di bottiglia, scenari con/senza paracadute, checklist
    organizzatori.
    Aggiunti modelli 3D STL: Fins Rev. 2 e Rev. 3, Soda Bottle Base Rev. 2.
    [Fins Rev. 2.stl, Fins Rev. 3 (corpo pieno + aggancio v2).stl, Soda Bottle Base Rev. 2.stl]
2026-06-14 Sostituisce polipropilene con cartone+nastro pacchi per le pinne
    Cartone ondulato da imballo riciclato (gratis, taglio con forbici, decorabile
    con qualsiasi medium) diventa il materiale principale per le pinne; il
    nastro da pacchi trasparente serve a laminarle impermeabilizzandole. Aggiunta
    procedura laminatura come mini-step didattico. Polipropilene corex resta come
    alternativa per uso ricorrente / variante avanzata.
    Specificato che ogni razzo farà 1-2 lanci massimo, coerente con la scelta
    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
2026-07-03 Add template stampabili delle pinne (HTML + PDF, 9 forme su 3 pagine A4)
    Template A4 in scala 1:1 con righello di calibrazione, 3 pagine tematiche:
    - Pagina 1 (classiche): trapezoidale, delta, freccia
    - Pagina 2 (extra): rettangolare, grande, ellittica
    - Pagina 3 (creative): ala di squalo, fiamma, foglia
    Ogni forma include dimensioni, descrizione e indicazione visiva del lato
    bottiglia. PDF generato da HTML via Edge headless, layout compresso per
    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
2026-09-03 Definisce la BOM elettronica con componenti scelti e verificati
    BOM (~99 €): 3x XIAO ESP32-S3 Sense con OV3660, 5x LiPo 1S 400 mAh 602040,
    10x cicalino attivo 12095, MPU6050, LED, pigtail JST 1.25. Antenna IPEX
    rimossa perché già inclusa nella confezione Seeed.
    Nuove sezioni in §13:
    - Alimentazione e ricarica: caricabatterie 1S integrato a 50 mA, polarità
    dei pad BAT, nessun ADC sulla batteria, niente cutoff di sottotensione
    - Buzzer attivo vs passivo, con specifiche del 12095 e collegamento
    diretto al GPIO (25 mA < 40 mA del limite per pin)
    - Pinout con camera + microSD attive: SD_CS su GPIO21 confligge con il LED
    onboard, restano 5 pad liberi, I2C su D4/D5
    - WiFi + BLE in coes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
2026-09-03 Riorganizza la documentazione elettronica e aggiunge l'indice
    La sezione 13 era cresciuta per accumulo fino a 600 righe con 20 titoli
    nell'ordine in cui erano emerse le domande, non in un ordine utile.
    - Sposta l'analisi dei sensori opzionali (high-g, BNO085, ADXL345,
    fascia dei 10 euro) nella nuova sezione 15, che apre con il registro
    delle decisioni. La 13 torna a essere un documento di montaggio.
    - Riordina la 13 per flusso di lavoro: architettura, board, sensori,
    alimentazione, pinout, buzzer, meccanica, firmware.
    - Fonde le due sezioni sul buzzer in una sola.
    - Il pinout assorbe bus I2C e schema di cablaggio; WiFi/BLE passa
    sotto architettura.
    - Condensa le note d'acquisto dell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
2026-10-03 Add firmware PlatformIO (pioarduino) per XIAO ESP32S3 Sense
    Progetto in firmware/ basato su pioarduino 55.03.312 (Arduino core 3.3.12,
    ESP-IDF 5.5.5). Sketch di test: LED lampeggiante, info chip/PSRAM su seriale,
    heartbeat ogni 2 s e ristampa info con Invio.
2026-10-03 Registratore di volo: video, audio e microSD sulla XIAO Sense
    - camera_rec: frame JPEG VGA della OV2640/OV3660 in video.mjpeg + frames.csv
    - audio_rec: microfono PDM in WAV 16 kHz/16 bit, header aggiornato ogni 2 s
    - storage: mount SD a 20 MHz con fallback, cartelle /REC_xxxx, elenco file,
    formattazione FAT32 da seriale (con conferma) per SD exFAT
    - main: avvio/stop da pulsante BOOT o seriale (r/s/i/l/h/F), AUTO_RECORD
    - flush periodico per non perdere dati se salta l'alimentazione
    Testato su scheda: OV3660, ~27.8 fps VGA, audio sincronizzato, 0 errori.
2026-10-03 Web server WiFi per scaricare e rivedere le registrazioni
    Access point "WaterRocket" (192.168.4.1 / rocket.local) con pagina web:
    stato e avvio/stop registrazione, anteprima camera, elenco sessioni con
    download/eliminazione e player nel browser (frame da video.mjpeg indicizzati
    con frames.csv, sincronizzati con audio.wav).
2026-10-03 Download AVI con audio e benchmark fps/SD
    - avi_export: genera al volo un AVI (MJPEG + PCM) da video.mjpeg,
    frames.csv e audio.wav, con indice idx1; i file su SD restano invariati
    - pagina web: pulsante "Video con audio" per ogni registrazione
    - comando seriale 'b': velocità di scrittura SD e fps reali della camera
    per ogni risoluzione
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2026-10-03 WiFi: collegamento opzionale a una rete esistente (AP + STA)
    Se include/secrets.h definisce WIFI_STA_SSID/WIFI_STA_PASS lo XIAO si
    collega a quella rete (es. hotspot del telefono) mantenendo attivo l'AP
    "WaterRocket". secrets.h è escluso da git; secrets.example.h come modello.
    Verificato dal PC sull'hotspot: API, pagina e download AVI (800x600,
    27.2 fps, 220 frame + audio, idx1 coerente).
2026-10-03 Piattaforma web dei lanci e web server asincrono
    - Web server su ESPAsyncWebServer: il WebServer sincrono si bloccava fino a
    5 s per ogni connessione preaperta dal browser (risposte 4-8 s); ora
    20-200 ms anche con richieste in parallelo
    - Avvio/stop dalla pagina passati al loop(), sessionDir protetta da mutex
    - AVI generato come sorgente ad accesso casuale (AviSource) per lo
    streaming asincrono
    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
2026-10-03 Guida al cablaggio con schemi: batteria, I2C, cicalino, anello LED
    - cablaggio.md: pinout, alimentazione e bilancio correnti, BMP280 +
    MPU6050 su I2C (D4/D5), cicalino attivo su D1, anello WS2812B 8 LED su
    D3 (VDD da BAT+, 330 ohm sul dato, 100 uF), montaggio, collaudo e
    checklist pre-volo
    - docs/img: sei schemi SVG (generale, pinout, batteria, I2C, cicalino,
    anello LED)
    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
2026-10-08 Cintura portaelettronica: due pod stampati sulla bottiglia
    - 3dModels/cintura: modello OpenSCAD parametrico. Pod elettronica con la
    XIAO su una slitta estraibile (bloccata da due perni di filamento) e la
    camera inclinata di 45° verso l'ugello, MPU6050 e BMP180 sul soffitto,
    cicalino sul fianco, anello LED sul tetto, antenna fuori sul fianco.
    Pod batteria con la stessa sagoma esterna e la LiPo in tasca, premuta
    dall'elastico. Due elastici nelle finestre dei fianchi; stampa
    capovolta senza supporti
    - Controlli di ingombro nel modello (componenti, estrazione della slitta,
    batteria), vista in spaccato, inquadratura automatica in OpenSCAD
    - STL e anteprime con misure provvisorie: b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
2026-10-16 Motivo dell'ultimo avvio nel comando 'i' e sblocco del bus I2C all'avvio
    - Riga "Avvio:" in 'i' e all'accensione: motivo dell'ultimo reset
    (accensione, USB, crash, watchdog, brownout...) e da quanto la scheda
    è accesa. Resta valido fino al reset successivo, quindi si scopre
    anche dopo perché la scheda si è riavviata da sola
    - Prima di Wire.begin 9 impulsi di clock e uno STOP: un reset a caldo a
    metà di una lettura lasciava l'MPU6050 con SDA basso e il primo
    tentativo falliva 2 volte su 10 ("controlla i contatti" senza motivo);
    dopo la modifica 0 su 20
    - Collaudo della scheda nuova cablata: sensori, cicalino, anello e
    registrazione a batteria (23,4 fps, 0 errori)
    Co-Authore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
